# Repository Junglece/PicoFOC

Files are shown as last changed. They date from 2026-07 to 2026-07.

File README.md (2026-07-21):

# PicoFOC

**紧凑型 STM32F103 无刷电机 FOC 驱动平台**

A compact STM32F103 BLDC FOC motor drive platform — firmware, PCB, and enclosure.



---

## 项目组成 / Structure

```
PicoFOC/
├── firmware/      STM32F103 FOC 固件 (Keil MDK-ARM)
│   ├── App/       业务逻辑层
│   ├── Bsp/       板级支持包
│   ├── Drv/       驱动层
│   ├── Lib/       纯数学算法（零硬件依赖）
│   ├── Core/      CubeMX 生成代码
│   ├── Drivers/   STM32 HAL + CMSIS
│   ├── MDK-ARM/   Keil 项目文件
│   └── tools/     辅助脚本
│
├── hardware/      PCB 设计 (EasyEDA / 立创 EDA)
├── mechanical/    3D 打印外壳（适配 2804 电机）
├── LICENSE        MIT License
└── README.md
```

## 固件 / Firmware

四层架构：**LIB**（纯数学，零硬件依赖）→ **BSP**（接口 + 实现）→ **DRV**（HAL 封装）→ **APP**（业务逻辑）。

- 主控 STM32F103C8T6，无 RTOS，纯中断驱动，1 kHz 控制频率
- CAN 1 Mbps + UART 115200 双协议通信
- 双观测器方案可选：差分观测器 / 龙伯格观测器

**Firmware:** 4-layer architecture (LIB→BSP→DRV→APP). STM32F103C8T6, bare-metal interrupt-driven, 1 kHz control loop. Dual CAN + UART communication. Optional difference / Luenberger observers.

详见 [firmware/README.md](firmware/README.md)。

## 硬件 / Hardware

- **主控 MCU**：STM32F103C8T6
- **驱动芯片 Driver**：MP6541（内置三相 MOS 功率桥、驱动电路与电流采样）
- **编码器 Encoder**：AS5600（I2C，12 位磁编码器）
- **CAN 收发器 CAN transceiver**：TJA1051，单路 CAN 外设、双物理接口支持设备串联
- **终端电阻 Termination**：板载可控 120Ω CAN 终端匹配电阻
- **调试接口 Debug**：SWD 下载与在线调试
- **通信接口 Communication**：UART 串口 + CAN
- **状态指示 Status**：板载 LED 指示灯
- **接口规格 Connectors**：PH2.0 / GH1.25
- **电源系统 Power**：12V 直流输入 → DCDC 12V 转 5V → LDO 5V 转 3.3V 全板供电；**无电源防反接保护**

详见 [hardware/README.md](hardware/README.md)。

## 机械 / Mechanical

3D 打印外壳，适配 2804 电机，包含三大部件：

- **磁环座** —— 固定径向充磁磁环，配合 AS5600 编码器
- **PCB外壳1** —— 下半部分，连接 PCB 与电机
- **PCB外壳2** —— 上半部分，PCB 上盖

螺丝规格：M3 / M2.5（平头）/ M2（平头）。如需适配不同电机，需自行修改外壳模型。

**3D-printed enclosure for 2804 motors.** Three parts: magnet holder (for radial magnet + AS5600), lower case (PCB-to-motor), upper case (PCB cover). Screws: M3 / M2.5 (flat-head) / M2 (flat-head). Modify models for different motors.

详见 [mechanical/README.md](mechanical/README.md)。

## 许可证 / License

MIT License，详见 [LICENSE](LICENSE)。

第三方组件：STM32 HAL Driver (BSD-3-Clause) · CMSIS (Apache-2.0)

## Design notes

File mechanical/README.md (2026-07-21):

# PicoFOC — Mechanical

3D 外壳与结构件设计。3D-printed enclosure and structural components.

---

## 文件结构

```
mechanical/
├── 建模文件/         CAD 源文件（STEP 格式）
│   ├── 2804电机定子.step       2804 电机定子模型（装配参考）
│   ├── 2804电机转子.step       2804 电机转子模型（装配参考）
│   ├── PicoFOC驱动板.step      PicoFOC 驱动板模型（装配参考）
│   ├── PCB外壳1.step           外壳下半部分 —— 连接 PCB 与电机
│   ├── PCB外壳2.step           外壳上半部分 —— PCB 上盖
│   └── 磁环座.step             磁环座 —— 固定径向充磁磁环到电机转轴
│
├── 打印文件/         3D 打印切片文件（3MF 格式）
│   ├── PCB外壳1.3mf
│   ├── PCB外壳2.3mf
│   └── 磁环座.3mf
│
└── README.md
```

## 三大部件

### 1. 磁环座
将径向充磁的磁环固定在 2804 电机转轴上，与驱动板上的 AS5600 磁编码器配合，实现转子位置检测。

### 2. PCB外壳1（下半部分）
连接 PCB 驱动板与 2804 电机的底座。内部容纳电机定子，上部固定 PCB。

### 3. PCB外壳2（上半部分）
PCB 驱动板的上盖，保护电路元件。

## 装配螺丝

| 规格 | 说明 |
|---|---|
| M3 | 外壳固定螺丝，长度按实际固定需求选取 |
| M2.5 | 螺丝需使用平头螺丝，沉孔空间有限 |
| M2 | 螺丝需使用平头螺丝，沉孔空间有限 |

## 电机适配

当前外壳针对 2804 电机设计。如需适配不同尺寸的电机，需自行修改外壳模型。

## 建模工具

STEP 文件可用任意主流 CAD 软件打开（Fusion 360、SolidWorks、FreeCAD 等）。
3MF 文件可直接导入切片软件（Bambu Studio、Orca Slicer、PrusaSlicer 等）进行打印。

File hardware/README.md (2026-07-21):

# PicoFOC — Hardware

电机驱动板硬件设计。Motor drive board hardware design.

---

## 设计工具

EasyEDA / 立创 EDA

## 文件清单

| 文件 | 说明 |
|---|---|
| `PicoFOC.epro2` | EDA 工程源文件 |
| `PCB_PCB1_PicoFOC.pdf` | 原理图 + PCB 布局 PDF |

## 硬件规格

- **主控**：STM32F103C8T6
- **驱动芯片**：MP6541（内置三相 MOS 功率桥、驱动电路与电流采样）
- **编码器**：AS5600（I2C，12 位磁编码器）
- **CAN 收发器**：TJA1051，单路 CAN 外设、双物理接口支持设备串联
- **终端电阻**：板载可控 120Ω CAN 终端匹配电阻
- **调试接口**：SWD 下载与在线调试
- **通信接口**：UART 串口 + CAN
- **状态指示**：板载 LED 指示灯
- **接口规格**：PH2.0 / GH1.25
- **电源系统**：12V 直流输入 → DCDC 12V 转 5V → LDO 5V 转 3.3V 全板供电；**无电源防反接保护**

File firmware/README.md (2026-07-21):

# STM32F103 FOC Motor Control Firmware

基于 STM32F103C8 的磁场定向控制（FOC）无刷电机驱动固件。

Field-Oriented Control (FOC) firmware for BLDC/PMSM motors on STM32F103C8.

---

## 概述 / Overview

本项目实现了一套完整的磁场定向控制（FOC）算法，运行在 STM32F103C8T6（Cortex-M3）上，驱动无刷直流电机（BLDC/PMSM）。核心特点：

- **四层分层架构**：LIB（纯数学）→ BSP（接口定义+实现）→ DRV（外设驱动封装）→ APP（业务逻辑编排）
- **依赖注入模式**：通过函数指针接口（Observer_t、AngleSensor_t、PwmOutput_t、NvStorage_t）实现硬件解耦
- **双通信协议**：CAN（标准帧，1Mbps）+ UART（自定义帧 + CRC16-CCITT）
- **双观测器**：差分观测器 + 龙伯格观测器可选
- **无 RTOS**：纯 TIM1 中断驱动，1kHz 控制频率

This project implements a complete FOC algorithm on STM32F103C8T6 (Cortex-M3) for BLDC/PMSM motors. Features include:

- **4-layer architecture**: LIB (pure math) → BSP (interface + implementation) → DRV (peripheral wrappers) → APP (business logic)
- **Dependency injection pattern**: Hardware decoupling via function pointer interfaces (Observer_t, AngleSensor_t, PwmOutput_t, NvStorage_t)
- **Dual communication**: CAN (standard frame, 1Mbps) + UART (custom frame + CRC16-CCITT)
- **Dual observers**: Difference observer + Luenberger observer
- **No RTOS**: Bare-metal TIM1 interrupt driven, 1kHz control rate

---

## 硬件要求 / Hardware Requirements

| 组件 / Component | 型号 / Model | 说明 / Notes |
|---|---|---|
| **MCU** | STM32F103C8T6 | Blue Pill 或自定义板 |
| **电机驱动** | 3 相逆变器 | DRV8301、L6234 或分立 MOS 桥 |
| **电机** | BLDC / PMSM | 带霍尔或编码器 |
| **编码器** | AS5600 | 12 位 I2C 磁编码器，地址 0x6C |
| **CAN 收发器** | SN65HVD230 | 或兼容的 3.3V CAN 收发器 |
| **调试** | ST-Link | 编程 + 调试 |

### 引脚定义 / Pinout

| 引脚 / Pin | 功能 / Function | 说明 / Notes |
|---|---|---|
| PA0, PA1, PA2 | ADC1_IN0~2 | 电流采样（预留，当前未使用） |
| PA5 | LED | 状态指示灯（PWM 亮度 + 闪烁模式） |
| PA6, PA7, PB0 | TIM3_CH1~3 | 三相 PWM 输出，中心对齐模式 |
| PA9, PA10 | USART1_TX/RX | 串口通信（VOFA+ just-float 调试协议） |
| PA11, PA12 | CAN_RX/TX | CAN 通信（1Mbps） |
| PB1 | GPIO OUT | 电机驱动使能（高电平有效） |
| PB6, PB7 | I2C1_SCL/SDA | AS5600 磁编码器接口 |

---

## 构建指南 / Build Instructions

### 前置条件 / Prerequisites

1. **Keil MDK-ARM 5.x**（推荐 5.38 或更新版本）
2. **ARM Compiler V5.06 update 6 (build 750)**（AC5 模式）
3. **STM32F1xx 器件包**（Keil Pack Installer 中安装）

### 步骤 / Steps

1. 打开 `MDK-ARM/FOC.uvprojx`
2. 在 Project 窗口确认所有源文件已加载
3. 点击 **Build (F7)** 或 **Rebuild All**
4. 预期结果：`0 Error(s), 0 Warning(s)`

---

## 使用方法 / Usage

### 上电流程 / Startup Sequence

1. 上电后 LED 呈心跳闪烁 → 系统初始化完成
2. 发送 **校准命令**（见下方协议）→ 电机注入 Ud=4V 对齐转子，LED 快闪
3. 校准完成后自动进入 **待机模式**，LED 心跳恢复
4. 发送 **位置/速度模式命令** → LED 根据扭矩实时调节亮度

### 状态机 / State Machine

```
POWER_ON → CALIBRATE → STANDBY → RUNNING (position/speed mode)
                ↑          │
                └──────────┘ (abort or complete)
```

---

## 通信协议 / Communication Protocol

### CAN 协议 / CAN Protocol

| 参数 | 值 |
|---|---|
| 波特率 | 1 Mbps |
| 帧格式 | 标准帧，8 字节数据 |
| 控制帧 ID | `0x000 + motor_id` |
| 状态帧 ID | `0x100 + motor_id` |

**8 字节 Payload 格式：**

| 字节 | 内容 | 类型 |
|---|---|---|
| [0] | 模式 (MODE) | uint8 |
| [1-4] | 目标值 (target) | float32 LE |
| [5-6] | Kp | uint16 LE |
| [7] | Kd / Ki | uint8 |

**模式定义：**

| 值 | 模式 | 说明 |
|----|---|---|
| 0x00 | STANDBY | 待机 |
| 0x01 | SPEED | 速度模式 |
| 0x03 | POSITION | 位置模式（角度控制） |
| 0x04 | CALIBRATE | 校准 |

### UART 协议 / UART Protocol

| 参数 | 值 |
|---|---|
| 波特率 | 115200 baud |
| 数据位 | 8 |
| 停止位 | 1 |
| 校验 | 无 |

**帧格式：**

```
[0xAA] [0x08] [8 bytes payload] [CRC16-CCITT LE]
```

- 8 字节 payload 格式与 CAN 协议相同
- CRC16-CCITT（多项式 0x1021），低位在前

**示例 / Examples：**

```
待机 (Standby)    : AA 08 00 00 00 00 00 00 80 00 A6 9A
位置 0° (Position): AA 08 03 00 00 00 00 00 80 00 D3 52
位置 10°          : AA 08 03 C2 B8 32 3E 00 80 00 15 74
校准 (Calibrate)  : AA 08 04 00 00 00 00 00 80 00 CB 95
```

### VOFA+ 调试协议

UART 同时支持 VOFA+ just-float 协议，用于实时波形调试：
- 每次 FOC 控制周期输出 6 个 float（电流 Id/Iq，角度，速度，目标值等）
- 使用 VOFA+ 上位机可直接查看波形

---

## 项目架构 / Architecture

```
FOC/
├── Lib/          纯数学算法，零硬件依赖
│   ├── pid.c/h           PID 控制器
│   ├── foc_math.c/h      坐标变换（Clarke/Park）
│   ├── observer_diff.c/h  差分观测器
│   ├── observer_luenberger.c/h  龙伯格观测器
│   └── data_process.c/h  角度处理工具
│
├── Bsp/          板级支持包（接口定义 + 硬件实现）
│   ├── angle_sensor.h    角度传感器抽象接口
│   ├── angle_as5600.c/h  AS5600 编码器实现
│   ├── pwm_output.h      三相 PWM 抽象接口
│   ├── pwm_3phase.c/h    TIM3 PWM 实现
│   ├── nv_storage.h      非易失存储抽象接口
│   ├── flash_storage.c/h 片内 Flash 存储实现
│   ├── observer.h        观测器抽象接口
│   └── motor_config.h    电机参数配置
│
├── Drv/          驱动层（HAL 外设封装）
│   ├── drv_tim.c/h       定时器时基驱动
│   ├── drv_can.c/h       CAN 原始收发
│   ├── drv_adc.c/h       ADC DMA 电流采样（预留）
│   └── led_indicator.c/h LED PWM + 模式状态机
│
├── App/          应用层（业务逻辑编排）
│   ├── Foc.c/h           FOC 控制器
│   ├── motor_ctrl.c/h    控制环状态机
│   ├── motor_msg.c/h     消息总线（编解码）
│   ├── can_proto.c/h     CAN 协议层
│   └── uart_proto.c/h    UART 协议层（含 CRC16 + VOFA+）
│
├── Core/          CubeMX 生成代码
│   ├── Src/main.c         主函数（用户代码段）
│   ├── Src/*.c            外设初始化代码
│   └── Inc/*.h            外设头文件
│
├── Drivers/       STM32 HAL + CMSIS（第三方，标准库）
│
├── MDK-ARM/       Keil 项目文件
│
└── Tools/         辅助脚本
    ├── gen_uart_cmd.ps1   UART 命令帧生成（PowerShell）
    ├── gen_uart_cmd.py    UART 命令帧生成（Python）
    └── gen_uart_cmd.js    UART 命令帧生成（Node.js）
```

---

## 许可证 / License

MIT License — 详见 [LICENSE](LICENSE) 文件。

本项目包含的第三方代码：
- **STM32 HAL Driver**: BSD-3-Clause © STMicroelectronics
- **CMSIS**: Apache 2.0 © ARM Limited

---

## 相关文档 / Related

- `Tools/gen_uart_cmd.ps1` — 生成带正确 CRC 的 UART 命令帧
- 协议详情见 [通信协议](#通信协议--communication-protocol)
- 如有疑问请提交 Issue

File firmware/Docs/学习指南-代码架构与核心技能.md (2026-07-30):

# PicoFOC 学习指南 —— 代码架构、设计模式与核心技能

> 本文档是从当前项目代码中提炼出的学习路线图。
> 你原来能写 PID、能写三环、能写控制逻辑，但不擅长抽象层、函数指针、架构分层。
> 这份指南帮你补齐这些短板，让你以后写代码（哪怕是交给 AI 写）也更懂自己要什么。

---

## 目录

1. [抽象接口模式（函数指针 + 结构体）](#1-抽象接口模式函数指针--结构体)
2. [四层架构（APP / DRV / BSP / LIB）](#2-四层架构app--drv--bsp--lib)
3. [工厂函数模式](#3-工厂函数模式)
4. [回调注册机制](#4-回调注册机制)
5. [消息总线模式](#5-消息总线模式)
6. [龙伯格观测器（完整链路）](#6-龙伯格观测器完整链路)
7. [FOC 控制流水线](#7-foc-控制流水线)
8. [安全防护链](#8-安全防护链)
9. [PID 时间归一化](#9-pid-时间归一化)
10. [static 隐藏内部状态](#10-static-隐藏内部状态)

---

## 1. 抽象接口模式（函数指针 + 结构体）

**这是你跟我写代码最大的差异点，也是整个架构的基石。**

### 1.1 这个模式解决了什么问题

你原来写代码的风格：

```c
// Foc.c 中直接调 HAL_I2C
uint8_t buf[2];
HAL_I2C_Mem_Read(&hi2c1, 0x6C, 0x0C, I2C_MEMADD_SIZE_8BIT, buf, 2, 50);
float angle = ((uint16_t)buf[0] << 8 | buf[1]) * (360.0f / 4096.0f);
```

这段代码的问题：
- FOC 控制器绑死了 AS5600 编码器
- 换编码器（比如换成 TLE5012 SPI）要改 Foc.c
- 要懂 I2C 才能看懂 Foc.c

**接口模式的做法：**

```c
// Foc.c 不知道什么 AS5600，它只跟接口打交道
float raw = sensor->read_angle(sensor->ctx);
//         ↑ 函数指针
//                           ↑ 上下文（谁实现的，谁提供数据）
```

### 1.2 四步法

#### 第①步：定义接口

接口文件只放函数指针结构体，不放任何硬件头文件。

**文件：`Bsp/Inc/angle_sensor.h`**

```c
#ifndef __ANGLE_SENSOR_H__
#define __ANGLE_SENSOR_H__

typedef struct AngleSensor_t AngleSensor_t;

struct AngleSensor_t
{
    /**
     * @brief  读取机械角度（0 ~ 360°）
     * @param  ctx : 实现方的上下文（通常是 I2C 句柄）
     * @return 机械角度（度）
     */
    float   (*read_angle)(void *ctx);

    void    *ctx;   /**< 上下文指针，如 &hi2c1 */
};

#endif
```

要点：
- 用结构体把**函数指针**和**上下文指针**打包在一起
- 注释写清楚每个指针参数的语义
- `void *ctx` 是万能钥匙——任何指针都能传

项目中一共 4 个接口文件：

| 接口文件 | 函数指针 | 用途 |
|---|---|---|
| `Bsp/inc/angle_sensor.h` | `read_angle` | 读角度 |
| `Bsp/inc/pwm_output.h` | `set_duty`, `enable`, `disable` | PWM 三相输出 |
| `Bsp/inc/nv_storage.h` | `read`, `write` | 非易失存储 |
| `Bsp/inc/observer.h` | `update`, `get_position`, `get_velocity` | 角度观测器 |

#### 第②步：实现接口

写一个 **.c 文件**，实现接口中定义的函数指针。

**文件：`Bsp/Src/angle_as5600.c`**

```c
#include "angle_as5600.h"
#include "i2c.h"

#define AS5600_ADDR      0x6C
#define AS5600_ANGLE_REG 0x0C

// 这个函数签名必须跟 angle_sensor.h 中的函数指针一致：
//   float (*read_angle)(void *ctx);
float AS5600_ReadAngle(void *ctx)
{
    I2C_HandleTypeDef *hi2c = (I2C_HandleTypeDef *)ctx;
    static float last_angle = 0.0f;
    uint8_t buf[2] = {0};
    uint16_t raw;

    if (HAL_I2C_Mem_Read(hi2c, AS5600_ADDR, AS5600_ANGLE_REG,
                         I2C_MEMADD_SIZE_8BIT, buf, 2, 50) != HAL_OK)
    {
        // I2C 读失败 → 返回上次有效角度，不产生角度跳变
        return last_angle;
    }

    raw = ((uint16_t)buf[0] << 8) | buf[1];
    last_angle = (float)raw * (360.0f / 4096.0f);
    return last_angle;
}
```

注意：
- 函数签名必须跟函数指针完全一致
- `ctx` 是 `void *`，用它之前要转型回真正的类型
- 这个文件可以包含 HAL 头文件（它是实现方，需要调硬件 API）

#### 第③步：工厂函数

工厂函数把函数指针和上下文粘到一起。

```c
// 还在 angle_as5600.c 中
AngleSensor_t AS5600_Create(I2C_HandleTypeDef *hi2c)
{
    AngleSensor_t sensor;
    sensor.read_angle = AS5600_ReadAngle;   // 填入函数指针
    sensor.ctx        = (void *)hi2c;       // 保存 I2C 句柄
    return sensor;
}
```

命名规范：`XXX_Create(参数) → 返回接口结构体`。

项目中所有工厂函数：

| 工厂函数 | 参数 | 返回答 |
|---|---|---|
| `AS5600_Create(hi2c)` | I2C 句柄 | `AngleSensor_t` |
| `PWM3Phase_Create(htim)` | TIM 句柄 | `PwmOutput_t` |
| `FlashStorage_Create(addr, magic, size)` | 地址/魔数/扇区大小 | `NvStorage_t` |
| `ObserverLuenberger_Create(cfg)` | 配置结构体指针 | `Observer_t` |

#### 第④步：使用接口

业务层通过函数指针调实现，完全不关心底层。

**文件：`App/Src/Foc.c`**

```c
// FOC_Init 中保存接口指针
foc->sensor   = sensor;    // 传入的是 AngleSensor_t *
foc->motor    = motor;     // PwmOutput_t *
foc->storage  = storage;   // NvStorage_t *
foc->observer = observer;  // Observer_t *

// 使用时通过函数指针调用
void FOC_UpdateSensor(FOC_t *foc)
{
    float raw = foc->sensor->read_angle(foc->sensor->ctx);
    //              ↑ 函数指针              ↑ 上下文
    foc->observer->update(foc->observer->ctx, raw);
    foc->mech_angle = foc->observer->get_position(foc->observer->ctx);
    foc->speed      = foc->observer->get_velocity(foc->observer->ctx);
}
```

### 1.3 换硬件要怎么改

假设你想把 AS5600（I2C 编码器）换成 TLE5012（SPI 编码器）：

```diff
// 只需要改 main.c 中的工厂调用，Foc.c/motor_ctrl.c 一行不动！

- AngleSensor_t sensor = AS5600_Create(&hi2c1);
+ AngleSensor_t sensor = TLE5012_Create(&hspi1);

  // 前提：TLE5012_Create() 返回的也是 AngleSensor_t
  // TLE5012_Create() 内部实现：
  //   static float TLE5012_ReadAngle(void *ctx) {
  //       SPI_HandleTypeDef *hspi = (SPI_HandleTypeDef *)ctx;
  //       // ... SPI 读代码 ...
  //       return angle;
  //   }
  //   AngleSensor_t TLE5012_Create(SPI_HandleTypeDef *hspi) {
  //       AngleSensor_t s;
  //       s.read_angle = TLE5012_ReadAngle;
  //       s.ctx = (void *)hspi;
  //       return s;
  //   }
```

换个板子（比如 STM32G4）同样道理——你只要保证新板子上的 BSP 层实现了这几个接口，APP 层不用改。

### 1.4 你可以在自己的项目中怎么用

```c
// 1. 定义接口
typedef struct {
    float (*read_temp)(void *ctx);
    void *ctx;
} TempSensor_t;

// 2. 实现 NTC 版本
float NTC_ReadTemp(void *ctx) { /* ADC 读 NTC */ }
TempSensor_t NTC_Create(ADC_HandleTypeDef *hadc) {
    TempSensor_t s;
    s.read_temp = NTC_ReadTemp;
    s.ctx = (void *)hadc;
    return s;
}

// 3. 实现 DS18B20 版本
float DS18B20_ReadTemp(void *ctx) { /* OneWire 读 */ }
TempSensor_t DS18B20_Create(...) { ... }

// 4. 业务代码中
void ControlTemp(TempSensor_t *s) {
    float t = s->read_temp(s->ctx);
    // 不管是什么传感器，都能用
}
```

---

## 2. 四层架构（APP / DRV / BSP / LIB）

### 2.1 各层职责

```
┌──────────────────────────────────────────────────────┐
│  APP（应用层）                                         │
│  负责控制逻辑、协议编解码、任务调度                     │
│  不应直接调 HAL                                         │
│                                                        │
│  App/Inc/Foc.h        App/Src/Foc.c                    │
│  App/Inc/motor_ctrl.h  App/Src/motor_ctrl.c             │
│  App/Inc/motor_msg.h   App/Src/motor_msg.c             │
│  App/Inc/can_proto.h   App/Src/can_proto.c             │
│  App/Inc/uart_proto.h  App/Src/uart_proto.c            │
├──────────────────────────────────────────────────────┤
│  DRV（驱动层）                                          │
│  封装 STM32 外设寄存器操作，向上提供简洁 API             │
│  是所有外设操作的唯一入口                                │
│                                                        │
│  Drv/Inc/drv_tim.h     Drv/Src/drv_tim.c              │
│  Drv/Inc/drv_can.h     Drv/Src/drv_can.c              │
│  Drv/Inc/drv_adc.h     Drv/Src/drv_adc.c              │
│  Drv/Inc/led_indicator.h Drv/Src/led_indicator.c      │
├──────────────────────────────────────────────────────┤
│  BSP（板级支持包）                                      │
│  板载外设的具体实现 + 抽象接口定义                      │
│  换板子 = 换这一层                                      │
│                                                        │
│  Bsp/Inc/angle_sensor.h  Bsp/Inc/pwm_output.h         │
│  Bsp/Inc/nv_storage.h    Bsp/Inc/observer.h           │
│  Bsp/Inc/motor_config.h                                │
│  Bsp/Src/angle_as5600.c  Bsp/Src/pwm_3phase.c         │
│  Bsp/Src/flash_storage.c                               │
├──────────────────────────────────────────────────────┤
│  LIB（纯算法层）                                        │
│  零硬件依赖，纯 C 数学运算                              │
│  可以直接复制到任何平台（PC/Arduino/ESP32）              │
│                                                        │
│  Lib/Inc/pid.h          Lib/Src/pid.c                  │
│  Lib/Inc/foc_math.h     Lib/Src/foc_math.c             │
│  Lib/Inc/data_process.h Lib/Src/data_process.c         │
│  Lib/Src/observer_luenberger.c                         │
└──────────────────────────────────────────────────────┘
```

### 2.2 铁律

```
APP 可以 include: DRV, BSP, LIB
DRV 可以 include: BSP, LIB
BSP 可以 include: LIB
LIB 不 include 任何非标准库头文件（只 include <stdint.h>, <math.h> 等）

反向禁止！
  DRV 不能 include APP
  BSP 不能 include APP 或 DRV
  LIB 不能 include APP、DRV 或 BSP
```

### 2.3 为什么这样分

| 场景 | 要改的层 | 不用动的层 |
|---|---|---|
| 换单片机（F103→F405） | DRV（HAL 调用不同） | APP, BSP(接口), LIB |
| 换编码器（AS5600→TLE5012） | BSP（新建实现文件） | APP, DRV, LIB |
| 换存储介质（Flash→EEPROM） | BSP（新建实现文件） | APP, DRV, LIB |
| 改 FOC 控制算法 | APP(Foc.c) | DRV, BSP, LIB |
| 移植到 PC 仿真算法 | LIB 直接复制 | — |

---

## 3. 工厂函数模式

工厂函数是一个"构造函数"，它把实现细节隐藏在内幕，返回一个已经配置好的接口结构体。

### 3.1 标准模板

```c
// 在实现文件（.c）的末尾
ReturnType_t XX_Create(参数)
{
    static XX_Ctx_t ctx;       // 静态存储——生命周期持续到断电

    ctx.param1 = param1;       // 存入参数
    ctx.param2 = param2;

    ReturnType_t obj;
    obj.func1 = XX_Func1;      // 填入函数指针
    obj.func2 = XX_Func2;
    obj.ctx   = &ctx;          // 上下文指向内部状态

    return obj;                // 返回结构体（栈上拷贝，轻量）
}
```

### 3.2 项目中 4 个工厂函数的对比

| 工厂函数 | 内部状态（ctx 指向什么） | 初始化工作 |
|---|---|---|
| `AS5600_Create(hi2c)` | 无内部状态，ctx 直接存 I2C 句柄 | 无（HAL 已经初始化好） |
| `PWM3Phase_Create(htim)` | 无内部状态，ctx 存 TIM 句柄 | 启动三路 PWM 通道 |
| `FlashStorage_Create(addr, magic, size)` | 存 Flash 地址/魔数/扇区大小 | 无（硬件已经初始化） |
| `ObserverLuenberger_Create(cfg)` | 存 l1/l2/Ts/x2_max/x1_hat/x2_hat | 清零所有状态初始化 |

### 3.3 你以后怎么用

```c
// 不管什么硬件，统一用一个工厂函数创建实例
// 所有配置都在这一个函数调用里完成
TempSensor_t temp = NTC_Create(&hadc1);
// 或者
TempSensor_t temp = DS18B20_Create(&huart2);

// 使用的时候完全一样
float t = temp.read_temp(temp.ctx);
```

---

## 4. 回调注册机制

### 4.1 解决的问题

你原来会在中断里直接写业务逻辑：

```c
// ❌ 原来的写法：修改业务逻辑必须进中断文件
void HAL_TIM_PeriodElapsedCallback(TIM_HandleTypeDef *htim) {
    Motor_Loop();           // 业务逻辑写死在中断文件里
    HAL_GPIO_TogglePin(...); // 测试代码也混在里面
}
```

### 4.2 现在的做法

**第①步：驱动层提供注册函数**

```c
// drv_tim.c
typedef void (*TIM_Callback_t)(void);  // 回调类型

static TIM_Callback_t user_callback = NULL;  // 静态保存回调指针

void TIM_RegisterCallback(TIM_Callback_t cb) {
    user_callback = cb;     // 注册就是把函数指针存下来
}
```

**第②步：中断只调回调**

```c
// drv_tim.c
void HAL_TIM_PeriodElapsedCallback(TIM_HandleTypeDef *htim) {
    if (htim == &htim1) {
        LED_Tick();                  // 硬件相关：LED 驱动
        // ...
        if (user_callback != NULL) {
            user_callback();         // → Motor_Loop()
        }
    }
}
```

**第③步：main.c 中注册**

```c
// main.c
TIM_RegisterCallback(Motor_Loop);    // 把业务函数地址传进去
```

**CAN 也是同样的模式：**

```c
// drv_can.c
static CAN_RxCallback_t rx_callback = NULL;

void CAN_RegisterRxCB(CAN_RxCallback_t cb) {
    rx_callback = cb;
}

// 中断中：
void HAL_CAN_RxFifo0MsgPendingCallback(...) {
    if (rx_callback != NULL) {
        rx_callback(id, data);  // → CANProto_RxCallback()
    }
}

// main.c
CANProto_Init(1);  // 内部会调 CAN_RegisterRxCB
```

### 4.3 好处

- **中断文件不变**：不管业务逻辑怎么改，`stm32f1xx_it.c` 和 `drv_tim.c` 不需要再改
- **可替换**：`TIM_RegisterCallback(Motor_Loop)` 换成 `TIM_RegisterCallback(Other_Loop)` 即可切换业务
- **可空检查**：`if (cb != NULL)` 防止未注册时调空指针

---

## 5. 消息总线模式

### 5.1 架构图

```
                    ┌─────────────────────────────────────┐
                    │          motor_msg.c                │
                    │                                     │
 CAN 数据流 ──────→ │  OnFrameReceived() → 解码 → 存储    │
 UART 数据流 ─────→ │  OnFrameReceived() → 解码 → 存储    │
                    │                                     │
                    │  PollCommand() ←── motor_ctrl 每 1ms │
                    │                                     │
                    │  TxStatus() ──→ CANProto_SendPayload │
                    │  TxStatus() ──→ UARTProto_SendPayload│
                    └─────────────────────────────────────┘
```

### 5.2 数据流详解

**接收路径（主机命令 → 电机控制）：**

```
① CAN 总线收到一帧
   → CAN1_RX0_IRQHandler
     → HAL_CAN_IRQHandler
       → HAL_CAN_RxFifo0MsgPendingCallback (在 drv_can.c)
         → rx_callback(id, data)    ← 注册的是 CANProto_RxCallback
           → MotorMsg_OnFrameReceived(MSG_CH_CAN, payload)
             → 解码 payload → 存到 g_cmd
               → 设置 g_new_frame = 1

② 或 UART 收到一帧
   → USART1_IRQHandler
     → HAL_UART_IRQHandler
       → uart_rx_handler(byte)       ← UART 状态机
         → 找 0xAA → 收 8 字节 → 校验 CRC
           → MotorMsg_OnFrameReceived(MSG_CH_UART, payload)
             → 同上

③ Motor_Loop 每 1ms：
   → MotorMsg_PollCommand(&cmd)
     → g_new_frame 为真时返回解码后的指令
       → cmd.mode / cmd.target / cmd.kp / cmd.ki
```

**发送路径（电机状态 → 上位机）：**

```
① Motor_Loop 每 1ms：
   → MotorMsg_UpdateStatus(角度, 速度, Vq)
     → 编码到 g_tx_payload
    
   → MotorMsg_TxStatus()
     → CANProto_SendPayload(g_tx_payload)  ← 总是发
     → if (UART模式) UARTProto_SendPayload(g_tx_payload)
```

### 5.3 双模切换

```c
// motor_msg.c
static uint32_t g_last_can_rx = 0;

void MotorMsg_OnFrameReceived(MotorMsg_Channel_t ch, const uint8_t data[8]) {
    if (ch == MSG_CH_CAN) {
        g_last_can_rx = HAL_GetTick();  // 记录 CAN 最后收帧时间
    }
    // ... 解码 ...
}

// 判断当前通信模式
uint8_t MotorMsg_IsCANMode(void) {
    return (HAL_GetTick() - g_last_can_rx) < 500;  // 500ms 超时
}
```

| 模式 | 条件 | CAN 自定义协议 | UART 自定义协议 | VOFA+ 调试 |
|---|---|---|---|---|
| CAN 模式 | 500ms 内收到过 CAN 帧 | ✓ 发 | ✗ 停发 | ✓ 全速发 |
| UART 模式 | 超过 500ms 没收 CAN | ✓ 发（可共存） | ✓ 发 | ✗ 停发 |

---

## 6. 龙伯格观测器（完整链路）

### 6.1 它解决什么

编码器读到的角度中混杂了噪声（I2C 通信噪声、量化误差、振动）。

你原来的做法——差分法：

```
speed = (angle_now - angle_last) × frequency × 6
```

如果角度有 ±1° 的噪声，在 1kHz 控制频率下速度噪声 = ±6000°/s = ±1000rpm。速度环看到这么大的噪声波动，输出会剧烈抖动。

龙伯格观测器的做法：

```
内部维护一个"模型"，模型自己会推演位置和速度
用实测角度去"修正"模型的推演结果
模型输出的位置和速度天然平滑（就像一个有惯性的滤波）
```

### 6.2 数学模型

**二阶状态空间模型：**

```
状态向量 x = [x1  ]    x1 = 估计位置 (度)
             [x2]      x2 = 估计速度 (rpm)

每个控制周期（Ts = 1/1000 = 0.001s 做两件事：

① 预测（先验估计）——用物理模型推演
  x1_k+1 = x1_k + Ts × x2_k × 6   ← 位置增量 = 速度 × 6(deg/s per rpm) × Ts
  x2_k+1 = x2_k                     ← 速度不变（匀速假设）

② 校正（后验修正）——用实测角度纠偏
  error = y_k - x1_k                ← y_k = 实测角度
  x1_k+1 += l1 × error              ← 位置偏差按 l1 比例修正
  x2_k+1 += l2 × error              ← 速度偏差按 l2 比例修正
```

### 6.3 完整代码

```c
// Lib/Src/observer_luenberger.c

// 内部状态
typedef struct {
    float x1_hat;   // 估计位置 (deg)
    float x2_hat;   // 估计速度 (rpm)
    float l1, l2;   // 校正增益
    float Ts;       // 采样周期 (s)
    float x2_max;   // 速度限幅
} ObserverLuenbergerCtx_t;

// 核心更新函数——每 1ms 调一次
static void luenberger_update(void *ctx, float raw_angle_deg)
{
    ObserverLuenbergerCtx_t *c = (ObserverLuenbergerCtx_t *)ctx;

    // 误差 = 实测 - 估计（取最短路径，不是简单减法）
    float error = ANGLE_limit(raw_angle_deg - c->x1_hat, 360.0f, -180.0f, 180.0f);

    // 预测 + 校正（合在一起写了）
    // rpm × 6 = deg/s, deg/s × Ts = deg
    c->x1_hat += c->Ts * c->x2_hat * 6.0f + c->l1 * error;
    c->x1_hat  = ANGLE_limit(c->x1_hat, 360.0f, 0.0f, 360.0f);

    c->x2_hat += c->l2 * error;
    c->x2_hat  = DATA_limit(c->x2_hat, -c->x2_max, c->x2_max);
}
```

### 6.4 调用链路

```
main.c 初始化：
  Observer_t angle_obs = ObserverLuenberger_Create(&obs_cfg);
  FOC_Init(&Motor, ..., &angle_obs);

每 1ms 控制周期（Motor_Loop → FOC_UpdateSensor）：
  
  ① foc->sensor->read_angle(foc->sensor->ctx)     ← AS5600 读原始角度
                    │
  ② foc->observer->update(ctx, raw_angle)         ← 喂给观测器
                    │
  ③ foc->observer->get_position(ctx)               ← 拿滤波后角度
     foc->observer->get_velocity(ctx)               ← 拿估计速度
                    │
  ④ 这两个值进入控制环：
     foc->mech_angle → 位置环 PD
     foc->speed      → 速度环 PI
```

### 6.5 调参指南

```c
ObserverLuenberger_Config obs_cfg = {
    .rate_hz   = 1000.0f,     // 控制频率
    .l1        = 0.14f,       // 位置校正增益
    .l2        = 100.0f,      // 速度校正增益
    .speed_max = 10000.0f,    // 速度限幅
};
```

| 应用场景 | l1 | l2 | 效果 | 适合 |
|---|---|---|---|---|
| 平衡模式 | 0.14 | 100 | 滤波和响应均衡 | 多数情况 |
| 重滤波 | 0.05 | 0.5 | 速度平滑但滞后 | 传感器噪声大 |
| 快响应 | 0.20 | 5.0 | 快速跟踪，速度有小抖动 | 外部扰动大 |
| 高刚度位置环 | 0.50 | 1.0 | 位置跟踪滞后 ~2ms | 位置模式 |

运行时动态调参：

```c
// 跑的过程中想改增益，不用重建
ObserverLuenberger_SetGain(&angle_obs, 0.2f, 150.0f);
```

### 6.6 换观测器

```c
// main.c —— 就换一行工厂函数
// 差分法：
// Observer_t angle_obs = ObserverDiff_Create(FOC_RATE_HZ);

// 龙伯格（当前）：
Observer_t angle_obs = ObserverLuenberger_Create(&obs_cfg);

// 卡尔曼（预留，接口相同）：
// Observer_t angle_obs = ObserverKalman_Create(&kalman_cfg);

// FOC_Init 中只保存 observer 指针，不管具体算法
```

---

## 7. FOC 控制流水线

### 7.1 单周期流水线

每 1ms，`Motor_Loop` 执行以下步骤：

```
① FOC_UpdateSensor(&Motor)
   └─→ sensor->read_angle() → observer->update() → get_position/get_velocity

② FOC_ReadCurrents(&Motor)          [封存，恒输出 0]
   └─→ 读 ADC → Clarke 变换 → Park 变换 → Id / Iq
        （当前无电流反馈，全部返回 0）

③ 控制环（根据模式选执行）：
   ┌─ 位置模式：FOC_PosCtrl(&Motor) + FOC_SpdCtrl(&Motor)
   │    位置 PD → 目标速度 → 速度 PI → Uq
   │
   ├─ 速度模式：FOC_SpdCtrl_Ext(&Motor)
   │    速度 PI（独立的 PID 参数）→ Uq
   │
   ├─ 待机模式：什么都不做（不调 FOC_Output）
   │
   └─ 校准模式：FOC_Output 中检测到 calib_flag, 自动注入 Ud=4V

④ FOC_Output(&Motor)
   └─→ 电角度前馈补偿
     └─→ (Ud, Uq) 矢量限幅（防止过调制）
       └─→ InvPark 变换：d-q → α-β
         └─→ InvClarke SVPWM：α-β → 三相电压
           └─→ 归一化 [0,1] → motor->set_duty()
```

### 7.2 关键数学变换

**反 Park 变换（d-q → α-β）：**

```
Ualpha = Ud × cos(θ) - Uq × sin(θ)
Ubeta  = Uq × cos(θ) + Ud × sin(θ)

其中 θ = 电角度 + 前馈补偿角度
```

**SVPWM（零序分量注入法）：**

```
① 用反 Clarke 算出三相电压（不含直流偏置）
② 找三相中的 Vmax 和 Vmin
③ Vzero = (Vmax + Vmin) / 2    ← 零序分量
④ Va -= Vzero; Vb -= Vzero; Vc -= Vzero;  ← 每相减去零序
⑤ 再叠加 Udc/2 偏置，使范围到 [0, Udc]
⑥ 归一化到 [0, 1] 输出给 PWM

等价于经典 SVPWM，但不需要扇区判断和切换时间计算。
直流利用率 ~100%（对比 SPWM 的 86.6%）。
```

### 7.3 电角度前馈补偿

```
问题：从 AS5600 采样到 PWM 输出生效，总共延迟 ~210μs
      高速时（比如 2000rpm, 7 极对）, 转子在此期间转过：
      2000 × 7 × 6 × 0.00021 = 17.6° 电角度
      如果不补偿，电压矢量滞后转子 17.6°，部分电压跑到 d 轴

补偿方法：
  FOC_Output 中，先用当前速度算出补偿角度
  加到电角度上再做反 Park 变换
  
代码（Foc.c）：
  float angle_advance = speed × pole_pairs × 6 × ANGLE_COMP_DELAY_S;
  float comp_elec_angle = foc->elec_angle + angle_advance;
  FOC_Math_InvPark(Ud, Uq, comp_elec_angle * DEG_TO_RAD, ...);
```

---

## 8. 安全防护链

### 8.1 三层防护

```
第一层：通信超时（软件）
  位置/速度模式下 100ms 没收指令 → 自动待机关断

第二层：异常中断（硬件+软件）
  NMI / HardFault / BusFault / MemManage / UsageFault
  全部做的第一件事：PB1 拉低（关 MP6541）

第三层：独立看门狗（硬件）
  2s 不喂狗 → MCU 自动复位
```

### 8.2 看门狗配置

```c
static void IWDG_Init(void)
{
    // ① 开启 LSI 时钟
    RCC->CSR |= RCC_CSR_LSION;
    while (!(RCC->CSR & RCC_CSR_LSIRDY));

    // ② 解锁
    IWDG->KR = 0x5555U;

    // ③ 预分频 /256: 40kHz / 256 = 156.25Hz
    IWDG->PR = 0x06U;

    // ④ 重装载 312: 312 / 156.25 = ~2.0s
    IWDG->RLR = 0x0138U;

    // ⑤ 刷新 + 启动
    IWDG->KR = 0xAAAAU;   // 刷新
    IWDG->KR = 0xCCCCU;   // 启动
}
```

喂狗点：
```c
// while(1) 主循环中
while (1) {
    IWDG_REFRESH();
    VOFA_SendDebug();
}

// Motor_Loop 每 1ms 周期
void Motor_Loop(void) {
    IWDG_REFRESH();   // 如果这里卡死，2s 后 WDT 复位
    // ...
}
```

---

## 9. PID 时间归一化

### 9.1 区别

```c
// ❌ 你原来的写法——积分累加不乘 dt，Ki 值依赖频率
pid->integral += error;
output = kp * error + ki * integral + kd * derivative;

// ✅ 现在的写法——积分乘 dt，Ki 值与频率无关
pid->integral += error * dt;     // dt = 1/rate
output = kp * error + ki * integral + kd * (differential / dt);
```

### 9.2 好处

如果你把 FOC_RATE_HZ 从 1000Hz 改成 500Hz：

- **旧的写法**：积分累加速率减半，Ki 效果实际翻倍，要重新调参
- **现在的写法**：`integral += error × dt` 中 dt 也翻倍了，Ki 效果完全不变

### 9.3 Derivative-on-Measurement

```c
// 旧写法——微分项 = Kd × (error - last_error)
// 目标值突变时 error 跳变 → 微分冲击
pid->differential = error - last_error;

// 新写法——微分项 = Kd × Δ测量值
// 目标值突变不影响微分项，只有测量值变化才会产生微分作用
pid->differential = measure_error;  // 当前位置 - 上次位置
// 位置环中：传入 -angle_delta 起阻尼作用
float angle_delta = mech_angle - last_mech_angle;
PID_Calc(&PosPID, error, -angle_delta);
```

---

## 10. static 隐藏内部状态

### 10.1 原则

```c
// 头文件中只放函数声明
// .c 文件中用 static 隐藏所有内部变量和辅助函数

// ❌ 不好——头文件中暴露内部变量
// drv_adc.h:
extern int16_t adc_dma_buf[3];  // 谁都能改

// ✅ 好——头文件只放 API 声明
// drv_adc.h:
void ADC_ReadPhaseCurrents(ADC_PhaseCurrents_t *currents);

// drv_adc.c:
static int16_t s_adc_dma_buf[3] = {0};    // 外部不可见
static int16_t s_adc_snapshot[3] = {0};
```

### 10.2 好处

- **可控的访问入口**：要读 ADC 数据只能通过 `ADC_GetRawCurrents()`，而不是直接读写数组
- **重构安全**：内部实现改了（比如数组大小变了），不影响外部调用代码
- **命名空间干净**：IDE 提示时不会看到一堆内部变量

---

## 总结：你应该带走的核心技能

| 技能 | 重要性 | 一句话说明 |
|---|---|---|
| 抽象接口模式 | ⭐⭐⭐ | 用 struct{函数指针; void *ctx} 把"干什么"和"怎么干"分离 |
| 四层架构 | ⭐⭐⭐ | APP/DRV/BSP/LIB，上层调下层，下层不能调上层 |
| 工厂函数 | ⭐⭐⭐ | `XXX_Create(参数) → 接口结构体`，对象的构造器 |
| 回调注册 | ⭐⭐ | 中断中不写业务逻辑，用 `RegisterCallback(func)` 挂上去 |
| 消息总线 | ⭐⭐ | 所有通信数据统一入口、统一解码，业务不需要知道来源 |
| static 封装 | ⭐⭐ | 内部变量用 static 隐藏，只通过 API 函数暴露 |
| 时间归一化 | ⭐⭐ | `integral += error × dt`，Ki 不再跟频率绑定 |
| 龙伯格观测器 | ⭐⭐ | 内部模型预测 + 实测值校正 → 平滑的位置和速度 |
| FOC 数学 | ⭐ | 反 Park → SVPWM 零序注入 → 归一化输出 |
| 前馈补偿 | ⭐ | 用当前速度推算延迟期间的角度偏移，提前补偿到输出角度 |

> **核心一条：** 以后再写代码，先想"这个功能将来会不会换硬件实现？"。如果会 → 用接口模式。
> 接口模式就三行——一个结构体、几个函数指针、一个 void *ctx。你完全能掌握。

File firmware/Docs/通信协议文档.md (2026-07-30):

# PicoFOC 通信协议文档

> 本文档描述 PicoFOC 电机控制器与上位机之间的通信协议。
> | 版本 | 日期 | 说明 |
> |------|------|------|
> | 1.2 | 2026-07-30 | 重构文档结构，新增编解码速查 + CRC16 参考实现 + 附录流程；修正 3.2 遗留的 `655.34` 系数 |
> | 1.1 | 2026-07-28 | VOFA 通道重映射；IWDG 初始化文档化 |
> | 1.0 | 2026-07-22 | 初始整理 |

---

## 1. 协议总览

### 1.1 双通信介质

PicoFOC 支持 **CAN** 和 **UART** 两种物理通信介质，两者独立运行、共用同一套 payload 格式。

| 介质 | 参数 | MCU 引脚 |
|---|---|---|
| CAN | 1 Mbps，标准帧（11 位 ID），8 字节数据 | PA11(RX), PA12(TX) |
| UART | 115200 8N1 | PA10(RX), PA9(TX) |

### 1.2 统一 8 字节 Payload 设计

CAN 和 UART 的**核心数据格式完全一致**——8 字节 payload 结构相同，编解码共用 `motor_msg.c` 同一套代码：

```
上位机 ──→ 电机 : [8 字节控制帧]   (RX 方向)
电机   ──→ 上位机 : [8 字节状态帧]   (TX 方向)
```

| 介质 | RX 控制帧 | TX 状态帧 |
|---|---|---|
| CAN | 裸 8 字节（ID=0x000+电机ID） | 裸 8 字节（ID=0x100+电机ID） |
| UART | `[0xAA][0x08][payload][CRC16]` | 同左 |

---

## 2. RX 控制帧（上位机 → 电机）

### 2.1 8 字节 Payload 布局

```
偏移:  [0]        [1][2][3][4]       [5][6]         [7]
      ┌──────────┬──────────────────┬──────────────┬──────────┐
      │  mode    │     target       │   kp_raw     │ kd_raw   │
      │  uint8   │   float32 LE     │  uint16 LE   │  uint8   │
      └──────────┴──────────────────┴──────────────┴──────────┘
```

### 2.2 mode — 运行模式（byte [0]）

| 值 | 名称 | 说明 |
|----|---|---|
| 0 | STANDBY | 待机，关断驱动芯片，PWM 停止，PID 积分清零 |
| 1 | TORQUE | 力矩模式（预留，未实现） |
| 2 | SPEED | 速度模式（独立速度 PI 环，使用 SpdPID_Ext） |
| 3 | POSITION | 位置模式（串级：位置 PD → 速度 PI） |
| 4 | CALIBRATE | 电角度自校准 |

> **边界处理：** 在 CAN/UART 协议层（收发回调中）做 `data[0] <= 4` 检查，mode 值 > 4 的帧**静默丢弃**。

### 2.3 target — 目标值（bytes [1..4]）

IEEE 754 **单精度浮点数、小端字节序**。单位取决于当前模式：

| 模式 | 物理含义 | 输入单位 | 内部换算 |
|---|---|---|---|
| SPEED | 目标机械角速度 | **rad/s** | `rpm = target × 9.5493` |
| POSITION | 目标机械角度 | **rad** | `deg = target × 57.2958` |
| CALIBRATE | 忽略 | — | — |
| STANDBY | 忽略 | — | — |

> **边界处理：** 解码后检查 IEEE 754 指数位（`0x7F800000`），NaN/Inf 自动替换为 0.0。

**常用角度换算表：**

| 角度 | 弧度 (float32) | 编码 HEX (LE) |
|---|---|---|
| 0° | 0.0 | `00 00 00 00` |
| 45° | 0.785398 | `49 0F C9 3F` |
| 90° | 1.570796 | `DB 0F C9 3F` |
| 180° | 3.141593 | `DB 0F 49 40` |
| 270° | 4.712389 | `DB 0F 96 40` |
| 280° | 4.886922 | `AA 61 9C 40` |
| 320° | 5.585054 | `C2 B8 B2 40` |
| 340° | 5.934119 | `4E E4 BD 40` |
| 360° | 6.283185 | `DB 0F C8 40` |

### 2.4 kp_raw — 比例增益（bytes [5..6]）

uint16 **小端**，**同时**设置位置环 Kp 和速度环 Kp。

| 属性 | 值 |
|---|-----|
| 解码公式 | `kp_float = raw × 0.00015259` |
| 编码公式 | `raw = round(kp_float / 0.00015259)` |
| 系数推导 | `10.0 / 65535 ≈ 0.00015259` |
| kp 范围 | **0.0 ~ 10.0** |
| raw 范围 | 0 ~ 65535 |
| 分辨率 | ~0.00015 |

**常用值速查：**

| kp_float | raw | HEX (LE) |
|---|-----|---|
| 0.0 | 0 | `00 00` |
| 0.01 | 66 | `42 00` |
| 0.05 | 328 | `48 01` |
| 1.0 | 6554 | `9A 19` |
| 3.0 | 19661 | `4D 4C` |
| **5.0** | **32768** | **`00 80`** |
| 10.0 | 65535 | `FF FF` |

### 2.5 kd_raw — 微分/积分增益（byte [7]）

一个 uint8 **同时编码**位置环 Kd 和速度环 Ki。

| 属性 | 值 |
|---|-----|
| 解码公式 | `kd_float = raw × 0.00392157`（写 pos_kd 和 spd_ki） |
| 编码公式 | `raw = round(kd_float / 0.00392157)` |
| 系数推导 | `1.0 / 255 ≈ 0.00392157` |
| kd/ki 范围 | **0.0 ~ 1.0** |
| raw 范围 | 0 ~ 255 |
| 分辨率 | ~0.00392 |

**常用值速查：**

| kd/ki_float | raw | HEX |
|---|-----|-----|
| 0.0 | 0 | `00` |
| 0.004 | 1 | `01` |
| 0.01 | 3 | `03` |
| 0.1 | 26 | `1A` |
| 0.5 | 128 | `80` |
| 1.0 | 255 | `FF` |

> ⚠️ **已知限制：** Kd 和 Ki 共用同一字节，无法独立设置。调位置环阻尼的同时会改变速度环积分，反之亦然。

### 2.6 CAN 控制帧

```
CAN ID = 0x000 + 电机ID  （标准帧，11 位）
默认（电机ID=1）：ID = 0x001
```

8 字节 payload 直接放入 CAN 数据场发送，**无额外帧头**。

### 2.7 UART 控制帧（完整 12 字节）

```
偏移: [0]    [1]    [2..9]          [10..11]
     ┌──────┬──────┬────────────────┬────────────┐
     │ 0xAA │ 0x08 │ 8-byte payload │ CRC16-CCITT│
     │ 帧头  │ 长度  │ （同 CAN）     │  小端       │
     └──────┴──────┴────────────────┴────────────┘
```

- **帧头（SOF）：** `0xAA`，用于接收状态机同步
- **长度字段：** 固定 `0x08`
- **CRC16-CCITT：** 对 SOF + LEN + 8 字节 payload 共 **10 字节**计算，小端存放
  - 多项式：`0x1021`，初始值：`0xFFFF`
  - 参考实现见第 [7 节](#7-crc16-ccitt-实现)
- **接收流程：** UART 中断 → 逐字节状态机 → 找 `0xAA` → 读长度 → 收 8 字节 payload → 收 2 字节 CRC → 校验 → 通过则解码
- **错误处理：** CRC 失败、长度不为 `0x08`、mode > 4 → 静默丢弃，状态机复位

---

## 3. TX 状态帧（电机 → 上位机）

### 3.1 8 字节 Payload 布局

```
偏移: [0..1]         [2..3]         [4..5]         [6..7]
     ┌──────────────┬──────────────┬──────────────┬──────────────┐
     │  位置 raw    │  速度 raw    │  Vq raw      │   保留       │
     │   int16 LE   │   int16 LE   │  int16 LE    │   = 0x0000  │
     └──────────────┴──────────────┴──────────────┴──────────────┘
```

编码通式：`raw = (int16_t)(物理量 × 编码系数)`

### 3.2 位置反馈（bytes [0..1]）

| 属性 | 值 |
|---|-----|
| 编码公式 | `raw = pos_rad × 834.4` |
| 解码公式 | `pos_rad = raw / 834.4` → `pos_deg = pos_rad × 57.2958` |
| 系数推导 | `32767 / (12.5 × π) ≈ 834.4` |
| 可编码范围 | **±39.27 rad（≈ ±2250°，约 6.25 圈）** |
| 分辨率 | **0.0012 rad ≈ 0.069°** |

### 3.3 速度反馈（bytes [2..3]）

| 属性 | 值 |
|---|-----|
| 编码公式 | `raw = speed_rads × 131.07` |
| 解码公式 | `speed_rads = raw / 131.07` → `rpm = speed_rads × 9.5493` |
| 系数推导 | `32767 / 250 ≈ 131.07` |
| 可编码范围 | **±250 rad/s（≈ ±2387 rpm）** |
| 分辨率 | **0.0076 rad/s ≈ 0.073 rpm** |

> 量程变更历史：2026-07-25 从 `655.34`（±477.5 rpm）改为 `131.07`（±2387 rpm）。

### 3.4 Vq 反馈（bytes [4..5]）

| 属性 | 值 |
|---|-----|
| 编码公式 | `raw = vq × 819.175` |
| 解码公式 | `vq = raw / 819.175` |
| 系数推导 | `32767 / 40 ≈ 819.175` |
| 可编码范围 | **±40 V** |
| 分辨率 | **0.00122 V** |

> 实际母线 12V，Vq 限幅在 ±12V，远在量程内，无饱和风险。

### 3.5 CAN 状态帧

```
CAN ID = 0x100 + 电机ID（标准帧，11 位）
默认（电机ID=1）：ID = 0x101
```

### 3.6 UART 状态帧

格式与 [2.7 UART 控制帧](#27-uart-控制帧完整-12-字节) 完全相同：`[0xAA][0x08][payload][CRC16 LE]`。

### 3.7 发送策略（双模自动切换）

状态帧每 1ms 发一次，CAN 和 UART 的发送策略不同：

```
每 1ms 控制周期：
  CANProto_SendPayload(payload)    ← 始终发送（CAN 总线 1kHz）
  if (UART 模式)                    ← 仅 500ms 内没收到 CAN 帧时
    UARTProto_SendPayload(payload)
```

**模式判定（500ms 超时）：**

| 模式 | 条件 | CAN 状态帧 | UART 自定义协议 | VOFA+ 调试 |
|---|---|---|---|---|
| **CAN 模式** | 最近 500ms 内收过 CAN 帧 | 1kHz ✓ | 停发 ✗ | 全速 ✓ |
| **UART 模式** | 超过 500ms 没收 CAN | 1kHz ✓ | 1kHz ✓ | 停发 ✗ |

---

## 4. VOFA+ 调试通道

### 4.1 帧格式

独立于自定义协议之上，与自定义协议**共用同一根 UART 线**。

```
[N × float32 (4N bytes)] [0x00, 0x00, 0x80, 0x7f]
  channel data              VOFA+ just-float 帧尾
```

- N = 8 通道，共 **36 字节/帧**
- 帧尾是 IEEE 754 的 +Inf（解释为 float 时 ≈ 1.1755e-38 非规范化数），VOFA+ 用它识别帧结束
- **同线共存：**
  - 自定义协议以 `0xAA` 开头 → VOFA+ 看到 `0xAA` 当无效浮点数忽略
  - VOFA 帧不以 `0xAA` 开头 → 自定义协议上位机（按 CRC 过滤）丢弃
  - `uart_tx_busy` 互斥锁防止两者同时发送

### 4.2 通道映射

| 通道 | 变量 | 单位 |
|---|---|---|
| ch0 | `Motor.mech_angle` | °（机械角度，观测器滤波后） |
| ch1 | `Motor.target_angle` | °（目标角度） |
| ch2 | `Motor.speed` | rpm（实际转速） |
| ch3 | `Motor.target_speed` | rpm（目标转速） |
| ch4 | `Motor.Uq` | V（交轴电压） |
| ch5 | `(float)MotorMsg_GetLastMode()` | —（运行模式 0~4） |
| ch6 | `MotorMsg_GetLastTarget()` | rad/rpm/Nm（最近指令目标值） |
| ch7 | `0.0f` | —（保留） |

### 4.3 发送条件

- **仅 CAN 模式**下发送（UART 模式停发，让出带宽给自定义协议）
- 由 `main.c` 的 `while(1)` 循环全速驱动
- 受 `uart_tx_busy` 互斥锁限制，实际约 1~2kHz

---

## 5. 常用指令速查表

### 5.1 CAN 帧（8 字节 payload，CAN ID = 0x001）

| 命令 | 8 字节 Payload (HEX) | 说明 |
|---|---|---|
| 待机 | `00 00 00 00 00 00 00 00` | mode=0 |
| 速度 50 rad/s ~477 rpm | `02 00 00 48 42 42 00 01` | kp=0.01, ki=0.004 |
| 位置 0° | `03 00 00 00 00 00 80 00` | kp=5.0 |
| 位置 45° | `03 49 0F C9 3F 00 80 00` | kp=5.0 |
| 位置 90° | `03 DB 0F C9 3F 00 80 00` | kp=5.0 |
| 位置 180° | `03 DB 0F 49 40 00 80 00` | kp=5.0 |
| 位置 280° | `03 AA 61 9C 40 00 80 00` | kp=5.0 |
| 位置 320° | `03 C2 B8 B2 40 00 80 00` | kp=5.0 |
| 位置 340° | `03 4E E4 BD 40 00 80 00` | kp=5.0 |
| 校准 | `04 00 00 00 00 00 80 00` | — |

### 5.2 UART 完整帧（12 字节）

| 命令 | 完整帧 (HEX) |
|---|---|
| 待机 | `AA 08 00 00 00 00 00 00 00 00 8A D1` |
| 速度 50 rad/s | `AA 08 02 00 00 48 42 42 00 01 EB BA` |
| 位置 0° | `AA 08 03 00 00 00 00 00 80 00 D3 52` |
| 位置 90° | `AA 08 03 DB 0F C9 3F 00 80 00 07 02` |
| 位置 180° | `AA 08 03 DB 0F 49 40 00 80 00 0B B4` |
| 位置 280° | `AA 08 03 AA 61 9C 40 00 80 00 0E 2A` |
| 校准 | `AA 08 04 00 00 00 00 00 80 00 CB 95` |

---

## 6. 编码系数速查表

| 方向 | 字段 | 公式 | 系数 | 推导 |
|---|---|---|---|---|
| **RX** | Kp | `float = raw × 系数` | **0.00015259** | `10.0 / 65535` |
| **RX** | Kd/Ki | `float = raw × 系数` | **0.00392157** | `1.0 / 255` |
| **TX** | 位置 | `raw = pos_rad × 系数` | **834.4** | `32767 / (12.5×π)` |
| **TX** | 速度 | `raw = speed_rads × 系数` | **131.07** | `32767 / 250` |
| **TX** | Vq | `raw = vq × 系数` | **819.175** | `32767 / 40` |

---

## 7. CRC16-CCITT 实现

用于 UART 帧校验（多项式 `0x1021`，初始值 `0xFFFF`）。

```c
/**
 * CRC16-CCITT 查表法
 * 输入数据：SOF(0xAA) + LEN(0x08) + 8-byte payload = 10 字节
 * 输出：16 位 CRC，小端存储（低字节在前，高字节在后）
 */

static const uint16_t crc16_table[256] = {
    0x0000, 0x1021, 0x2042, 0x3063, 0x4084, 0x50A5, 0x60C6, 0x70E7,
    0x8108, 0x9129, 0xA14A, 0xB16B, 0xC18C, 0xD1AD, 0xE1CE, 0xF1EF,
    0x1231, 0x0210, 0x3273, 0x2252, 0x52B5, 0x4294, 0x72F7, 0x62D6,
    0x9339, 0x8318, 0xB37B, 0xA35A, 0xD3BD, 0xC39C, 0xF3FF, 0xE3DE,
    0x2462, 0x3443, 0x0420, 0x1401, 0x64E6, 0x74C7, 0x44A4, 0x5485,
    0xA56A, 0xB54B, 0x8528, 0x9509, 0xE5EE, 0xF5CF, 0xC5AC, 0xD58D,
    0x3653, 0x2672, 0x1611, 0x0630, 0x76D7, 0x66F6, 0x5695, 0x46B4,
    0xB75B, 0xA77A, 0x9719, 0x8738, 0xF7DF, 0xE7FE, 0xD79D, 0xC7BC,
    0x48C4, 0x58E5, 0x6886, 0x78A7, 0x0840, 0x1861, 0x2802, 0x3823,
    0xC9CC, 0xD9ED, 0xE98E, 0xF9AF, 0x8948, 0x9969, 0xA90A, 0xB92B,
    0x5AF5, 0x4AD4, 0x7AB7, 0x6A96, 0x1A71, 0x0A50, 0x3A33, 0x2A12,
    0xDBFD, 0xCBDC, 0xFBBF, 0xEB9E, 0x9B79, 0x8B58, 0xBB3B, 0xAB1A,
    0x6CA6, 0x7C87, 0x4CE4, 0x5CC5, 0x2C22, 0x3C03, 0x0C60, 0x1C41,
    0xEDAE, 0xFD8F, 0xCDEC, 0xDDCD, 0xAD2A, 0xBD0B, 0x8D68, 0x9D49,
    0x7E97, 0x6EB6, 0x5ED5, 0x4EF4, 0x3E13, 0x2E32, 0x1E51, 0x0E70,
    0xFF9F, 0xEFBE, 0xDFDD, 0xCFFC, 0xBF1B, 0xAF3A, 0x9F59, 0x8F78,
    0x9188, 0x81A9, 0xB1CA, 0xA1EB, 0xD10C, 0xC12D, 0xF14E, 0xE16F,
    0x1080, 0x00A1, 0x30C2, 0x20E3, 0x5004, 0x4025, 0x7046, 0x6067,
    0x83B9, 0x9398, 0xA3FB, 0xB3DA, 0xC33D, 0xD31C, 0xE37F, 0xF35E,
    0x02B1, 0x1290, 0x22F3, 0x32D2, 0x4235, 0x5214, 0x6277, 0x7256,
    0xB5EA, 0xA5CB, 0x95A8, 0x8589, 0xF56E, 0xE54F, 0xD52C, 0xC50D,
    0x34E2, 0x24C3, 0x14A0, 0x0481, 0x7466, 0x6447, 0x5424, 0x4405,
    0xA7DB, 0xB7FA, 0x8799, 0x97B8, 0xE75F, 0xF77E, 0xC71D, 0xD73C,
    0x26D3, 0x36F2, 0x0691, 0x16B0, 0x6657, 0x7676, 0x4615, 0x5634,
    0xD94C, 0xC96D, 0xF90E, 0xE92F, 0x99C8, 0x89E9, 0xB98A, 0xA9AB,
    0x5844, 0x4865, 0x7806, 0x6827, 0x18C0, 0x08E1, 0x3882, 0x28A3,
    0xCB7D, 0xDB5C, 0xEB3F, 0xFB1E, 0x8BF9, 0x9BD8, 0xABBB, 0xBB9A,
    0x4A75, 0x5A54, 0x6A37, 0x7A16, 0x0AF1, 0x1AD0, 0x2AB3, 0x3A92,
    0xFD2E, 0xED0F, 0xDD6C, 0xCD4D, 0xBDAA, 0xAD8B, 0x9DE8, 0x8DC9,
    0x7C26, 0x6C07, 0x5C64, 0x4C45, 0x3CA2, 0x2C83, 0x1CE0, 0x0CC1,
    0xEF1F, 0xFF3E, 0xCF5D, 0xDF7C, 0xAF9B, 0xBFBA, 0x8FD9, 0x9FF8,
    0x6E17, 0x7E36, 0x4E55, 0x5E74, 0x2E93, 0x3EB2, 0x0ED1, 0x1EF0,
};

uint16_t CRC16_CCITT(const uint8_t *data, uint32_t len)
{
    uint16_t crc = 0xFFFF;
    for (uint32_t i = 0; i < len; i++)
    {
        crc = (crc << 8) ^ crc16_table[((crc >> 8) ^ data[i]) & 0xFF];
    }
    return crc;
}
```

> 位运算版本（适用于查表空间受限的场景）：
> ```c
> uint16_t CRC16_CCITT(const uint8_t *data, uint32_t len) {
>     uint16_t crc = 0xFFFF;
>     for (uint32_t i = 0; i < len; i++) {
>         crc ^= (uint16_t)data[i] << 8;
>         for (int j = 0; j < 8; j++)
>             crc = (crc & 0x8000) ? (crc << 1) ^ 0x1021 : (crc << 1);
>     }
>     return crc;
> }
> ```

---

## 8. 已知问题

| # | 问题 | 影响 | 备注 |
|---|---|---|---|
| 1 | byte[7] 同时编码 pos_kd 和 spd_ki | 无法独立调位置环阻尼和速度环积分 | 需扩展 payload 或用参数分组指令 |
| 2 | ~~速度反馈范围不足~~ | ~~已修复 2026-07-25~~ | 系数 655.34 → 131.07，量程扩至 ±2387 rpm |
| 3 | ~~NaN/Inf 未校验~~ | ~~已修复 2026-07-26~~ | DecodeCommand 中增加指数位检查 |
| 4 | VOFA+ ch5/ch6 为 float 强转 | mode/target 以浮点数形式发送 | VOFA+ 仅支持 float 类型，可接受 |

---

## 附录：完整发送流程速查

### 上位机发指令（控制帧）

```
① 决定模式、目标值、Kp、Kd → 填写 8 字节 payload
② CAN 方式：发到 ID = 0x000 + 电机ID（默认 0x001）
③ UART 方式：
   帧 = [0xAA][0x08][payload][CRC16_CCITT(10B) 小端]
   发到 UART（115200 8N1）
```

### 电机回传数据（状态帧，自动 1kHz）

```
① 电机每 1ms 编码 tx_payload：
     [0..1] = int16(g_pos_rad × 834.4)
     [2..3] = int16(g_spd_rads × 131.07)
     [4..5] = int16(g_vq × 819.175)
     [6..7] = 0x0000
② CAN 方式：ID = 0x100 + 电机ID（默认 0x101），始终发送
③ UART 方式：帧头封装同上，仅 UART 模式发送
④ VOFA+（仅 CAN 模式）：8×float + 帧尾，36 字节
```

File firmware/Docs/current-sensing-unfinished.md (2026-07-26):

---
name: current-sensing-unfinished
description: 电流环 Phase 1 剩余工作 + Phase 2 完整计划（已封存）
metadata:
  type: reference
---

# 电流环未完成部分说明

**封存日期：** 2026-07-26
**原因：** 小电机空载/轻载下，MP6541 SOx 电流检测信噪比不足，放弃电流环。

---

## Phase 1 完成项

| 项目 | 状态 | 说明 |
|---|---|---|
| mp6541_current.h 常量和公式 | ✅ | 换算系数、偏置、增益表 |
| drv_adc.h/c 驱动 | ✅ | DMA CIRCULAR + 快照 + ISR 读接口 |
| foc_math.h/c Clarke+Park | ✅ | 纯数学库，不依赖 ADC |
| Foc.h 电流字段 | ✅ | Ia/Ib/Ic/Ialpha/Ibeta/Id/Iq + current_raw |
| Foc.c FOC_ReadCurrents | ✅ | 读取→Clarke→Park 流水线 |
| main.c ADC_Init + VOFA 通道 | ✅ | 初始化 + 8 通道映射 |
| motor_ctrl.c 调 FOC_ReadCurrents | ✅ | 放在 FOC_UpdateSensor 之后 |

## Phase 1 未完成/有问题的项

| 项目 | 状态 | 详细 |
|---|---|---|
| ADC 采样与 PWM 同步 | ❌ 未解决 | 见 [[current-sensing-retrospective]] v3 分析 |
| TIM3 CC4 中断可靠触发 | ⚠️ 修复中 | CC4E 问题已发现，PWM mode 1 + CCR4=18 方案未验证 |
| 全周期电流波形 | ❌ 未验证 | 只能看到正半周，负半周因采样不同步被削 |
| 编译后实测 + VOFA 验证 | ❌ 未进行 | 代码改完未烧录完整验证 |

## Phase 2 所有内容（完全未动）

以下原本计划在 Phase 1 验证通过后实施：

### 2.1 电流环 PI 控制

- **Foc.h** 加字段: `target_iq`, `CurrPID_D`, `CurrPID_Q`
- **Foc.c** 加 `FOC_CurrCtrl()`: D 轴目标=0，Q 轴目标=target_iq，纯 PI
- **motor_ctrl.c** 改流水线为三环串级: **Pos→Spd→Curr**
- 速度环输出从 Uq 改为 target_iq（电流环算出的 Uq 才不会覆盖）
- **main.c** 加 `FOC_SetCurrPID` 配置

### 2.2 零电流校准

- **drv_adc.c** 实现 `ADC_CalibrateOffset()`: 暂停 DMA → 软件触发轮询 128 次取平均
- **motor_msg.h** 加 `CALIBRATE_CURRENT = 5`
- **led_indicator** 加 `CURRENT_CAL_BLINK` (200ms)
- **can_proto.c** mode 校验范围从 >4 改为 >5

### 2.3 Flash 版本迁移

- `CalibrationData_t` 结构体（含 version 字段）
- 旧版（4B float）→ 新版（含 version 判断）迁移逻辑

### 2.4 力矩模式

- mode=1（原 TORQUE）直接设 `target_iq`，不走速度环

## 封存后代码中可保留的部分

以下与电流相关、但不依赖 ADC 采样硬件的代码，**建议保留**：

- **foc_math.h/c** — Clarke/Park 变换是纯数学，后续无论用何种传感器都需用到
- **Foc.h** 中的 Ia/Ib/Ic/Id/Iq/Ialpha/Ibeta 字段 — 数据结构定义无害
- **FOC_ReadCurrents()** 调用链 — 当前已经被置零，FOC 仍然正常跑

## 恢复条件

如果未来以下任一条件满足，可以接续此工作：
1. **更换更大功率的电机**（额定电流 >1A）
2. **提高母线电压**（12V→24V+，电流信噪比提升）
3. **更换外置电流传感器**（ACS712/INA240 等专用芯片）
4. **PCB 改版**（优化 SOx 走线、加差分放大器）

恢复步骤见 [[current-sensing-retrospective#迁移建议]]。

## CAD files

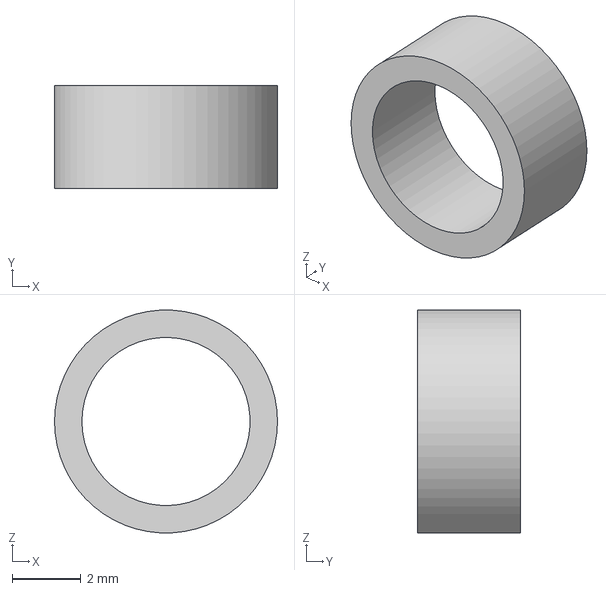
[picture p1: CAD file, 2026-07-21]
mechanical/建模文件/磁环座.step
6.50 x 3.00 x 6.49 mm

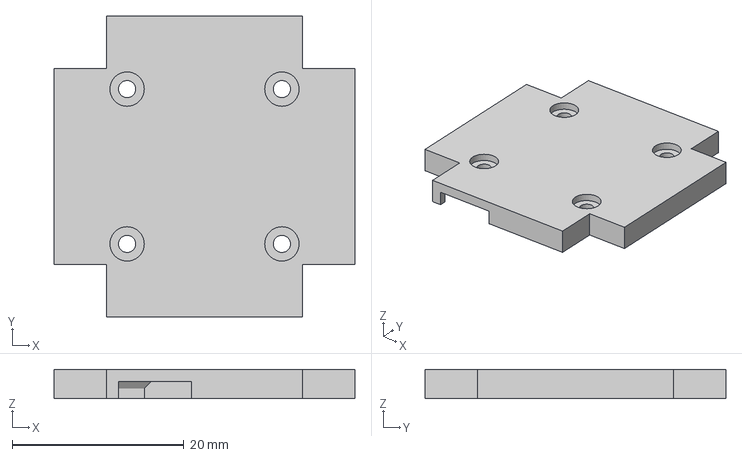
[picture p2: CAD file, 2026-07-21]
mechanical/打印文件/PCB外壳2.3mf
35.0 x 35.0 x 3.40 mm

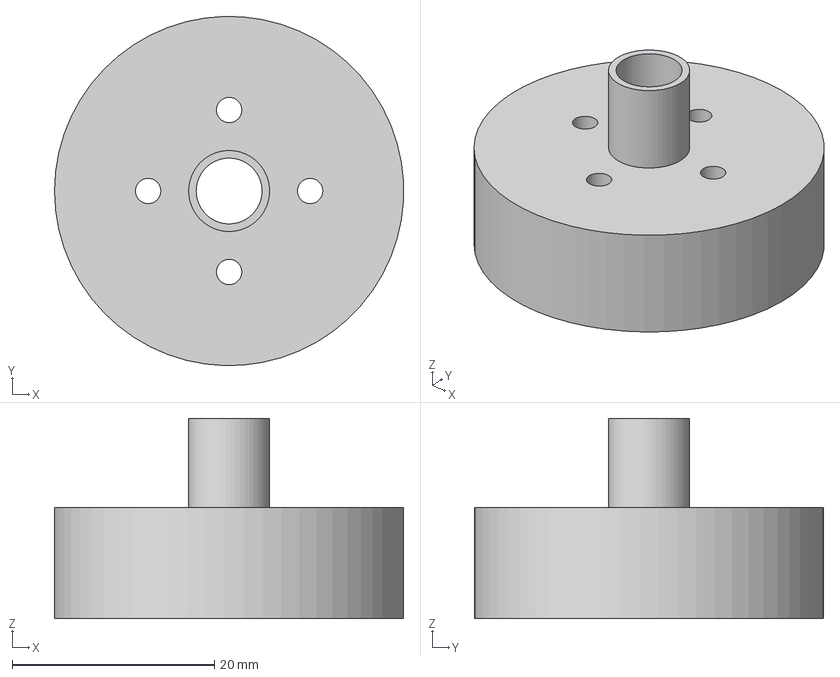
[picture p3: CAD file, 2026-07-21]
mechanical/建模文件/2804电机转子.step
34.5 x 34.5 x 19.8 mm

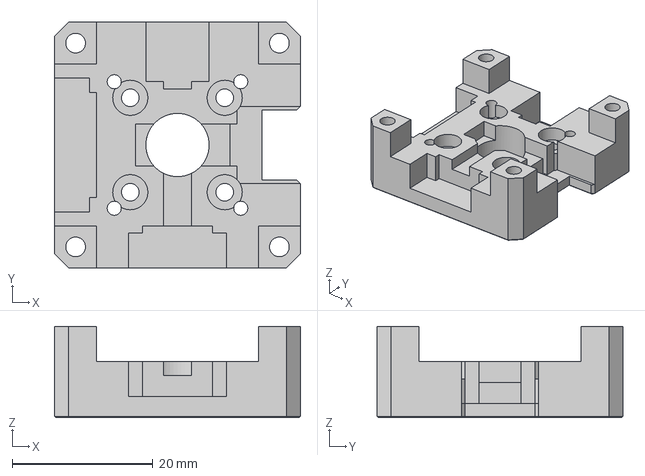
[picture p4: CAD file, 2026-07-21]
mechanical/建模文件/PCB外壳1.step
35.0 x 35.0 x 13.0 mm

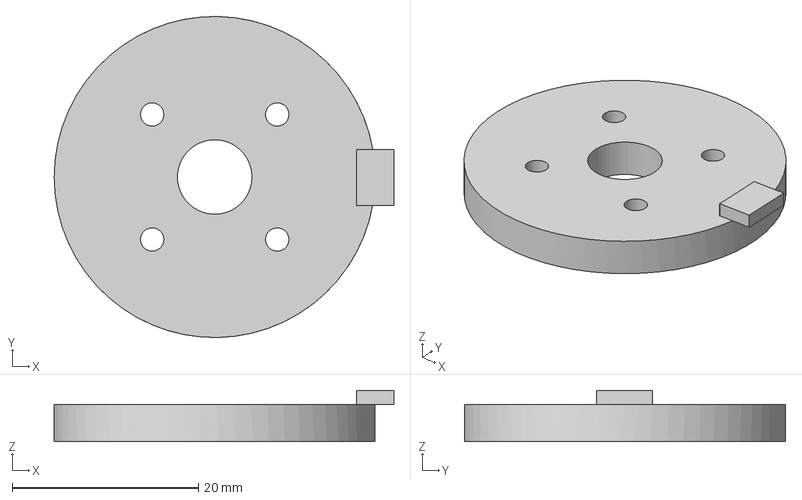
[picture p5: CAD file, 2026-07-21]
mechanical/建模文件/2804电机定子.step
36.5 x 34.5 x 5.50 mm

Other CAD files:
mechanical/打印文件/磁环座.3mf
mechanical/打印文件/PCB外壳1.3mf
mechanical/建模文件/PCB外壳2.step

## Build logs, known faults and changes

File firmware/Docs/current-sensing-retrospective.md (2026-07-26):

---
name: current-sensing-retrospective
description: ADC 电流采样方案试错经验总结（2026-07 已封存）
metadata:
  type: reference
---

# ADC 三相电流采样 — 试错经验总结

**状态：封存** — 该链路已启用但保留代码，供后续参考或硬件升级后复用。

---

## 背景

PicoFOC 使用 **MP6541** 一体式 BLDC 驱动器，其内部集成电流检测放大器（SOA/SOB/SOC 引脚输出），通过外部偏置网络（3.3V→5.1K→SOx→5.1K→GND → 1.65V + 2.55KΩ 等效）将相电流线性映射为电压信号，由 STM32F103C8T6 的 ADC1（PA0/PA1/PA2）采样。

## 问题现象

从"改对"到"改错"到"放弃"，共经历四次架构迭代。以下是每轮的方案、诊断、根因：

---

### v1：HW 触发 → TIM3 TRGO=OC4REF + CCR4=0

**目标：** 每个 PWM 周期在 V0（CNT=0）时刻硬件触发 ADC，DMA 自动搬运。

**CubeMX 配置：**
- TIM3 MasterOutputTrigger = OC4REF
- CH4 = PWM Generation no output, PWM mode 2, CCR4=0
- ADC1 ExternalTriggerConv = Timer 3 Trigger Out, ContinuousConv = DISABLE

**现象：** 三相电流恒为 -7.12A（(0-2048) × 0.003476）。

**根因：** STM32F1 上 TIMx_CH4 的 OC4REF 内部信号受 CC4E 位控制。CubeMX 中 CH4 设为 "PWM Generation no output" → CC4E=0 → OC4REF 被硬件强制拉低，永远无上升沿 → ADC 永远收不到触发 → DMA 缓冲保持 0。

**教训：** 在 F1 系列上，OC4REF 路径需要 CC4E=1 才能工作。即使引脚不输出，也要在 USER CODE 中手动 `TIM3->CCER |= TIM_CCER_CC4E`。

**修复尝试：** 在 tim.c USER CODE 中加 `TIM3->CCER |= TIM_CCER_CC4E` → AVOID（怕被 CubeMX 重置，但其实 USER CODE 不会被覆盖）。

---

### v2：HW 触发 → TIM3 TRGO=Update

**目标：** 改用 Update Event 触发 ADC（简单粗暴）。

**CubeMX 配置：**
- TIM3 MasterOutputTrigger = Update
- ADC1 ExternalTriggerConv = Timer 3 Trigger Out

**现象：** 能采到正弦波，但：
1. 只有上半周（正半周），负半周被削
2. 三角波变形 + 周期性 dropout（采几周期→全 0→再采到）
3. Id/Iq 形态倒是对的（正弦→Clarke→Park 后信息仍在）

**根因：** 中心对齐 PWM 模式下，Update Event 在 V0（CNT=0）和 V7（CNT=1799）各触发一次 → ADC 以 40kHz 双触发率运行。V7 时刻三个上管导通，SOx 反映的是高侧电流，偏置不同，且电机续流路径不同 → 读数不可用。DMA 缓冲区交替混入 V0 有效值和 V7 无效值 → FOC 1kHz 快照时随机读到 V0/V7 数据 → 波形畸变。

**教训：** 对于三相半桥驱动，电流采样只能在 V0（零矢量，低侧续流）时刻有效。任何在 V7 的采样都会读到错误值。Update Event 双触发无法被 F1 硬件过滤，必须避免。

---

### v3：ADC 连续自由转换 + DMA CIRCULAR + TIM3 CC4 中断

**目标：** ADC 完全自由连续转换（~98kHz，3 通道每 10.5µs 扫一轮），DMA CIRCULAR 持续更新。TIM3 CH4 在 V0 触发 CC4 中断，ISR 中读取 DMA 最新值。

**CubeMX 配置：**
- ADC1 ContinuousConvMode = ENABLE, ExternalTrigConv = ADC_SOFTWARE_START
- TIM3 MasterOutputTrigger = RESET（不参与 ADC 触发）
- CH4 = PWM Generation no output, PWM mode 2, CCR4=0（只用 CC4 中断做 V0 同步）

**现象：**
- 直接读 DMA 缓冲（`s_adc_dma_buf`）：能看到三相 ~120° 正弦波，但只有 2048 以上（正半周），负半周被削
- 断电能看到下降到 2048 以下，但正常运行负半周几乎看不到
- Id/Iq 仍有明显正弦成分

**根因（诊断过程）：**
1. 确认 DMA 缓冲区通过 VOFA+ ch5/6/7 原值读出 → 数据更新、波形存在 → **ADC + DMA 链路正常**
2. 用快照（`ADC_TakeSnapshot` 关中断拷贝） → 结果跟直读一样 → **竞态不是问题**
3. `Motor.current_raw` 一直为 0 → ISR 没执行 → 发现 **CC4E=0 导致 CC4IF 不置位** → 加 `TIM3->CCER |= TIM_CCER_CC4E`
4. CC4E 加上后仍为 0 → 怀疑 **CCR4=0 与更新事件竞争** → 改用 PWM mode 1 + CCR4=18（~1% 占空比）

**根本问题（未解决）：**
ADC 虽然是"自由连续转换"，**但它与 PWM 不同步**。DMA 缓冲区中存储的是最近一次完成的 ADC 扫描，而该扫描可能发生在 PWM 周期的任意时刻。TIM3 CC4 在 V0 附近触发并读取 DMA，读到的是**上一个任意时刻完成的转换结果**——可能来自 V0（偏置正确），也可能来自 V7 附近（电流换路、偏置异常）。因此正半周（V0 附近电流大时偶然对应 V0 采样）可见，负半周不可见。

**教训：**
- 在 STM32F1 上，**连续自由转换 + 定时中断读 DMA** 无法保证采样时刻与 PWM 同步
- 要真正同步，必须用硬件触发 ADC + DMA（回到 v1 思路）——但这需要正确配置 CC4E
- 或者用两个定时器：TIM3 发 PWM，TIM3_CH4 OC4REF 触发 ADC（需要 CC4E=1）
- 另一个方向：用 TIM1（20kHz 中断）触发软件 ADC 启动——但软件触发有抖动

---

### v4：PWM mode 1 + CCR4=18（尝试修复 v3）

**目标：** 用非零 CCR4 避开 CNT=0 的竞争，让 CC4 中断可靠触发。

**配置：** TIM3 CH4 在 CubeMX 初始化后手动覆盖：
- `TIM3->CCMR2 = (old & 0x8FFF) | 0x6000`  → PWM mode 1
- `TIM3->CCR4 = 18`

**结果：** 未验证（在调试中发现并修复 CC4E 后，用户决定放弃电流采样）。

**理论分析：** 即使 CC4 中断可靠触发，v3 的根本问题（ADC 采样与 PWM 不同步）仍然存在。因此这条路线本质上也无法解决波形削波问题。

**结论：** 需要同时做两件事——① CC4E=1 让中断能触，② 回到 HW 触发 ADC（TIM3 TRGO=OC4REF + CC4E=1），让 ADC 在 V0 时刻被硬件启动采样，才能保证同步。

---

## 硬件限制分析

在调试过程中确认的小电机空载/轻载电流特征：
- 小电机（如本项目的 7 对极微型 BLDC）在空载/轻载时，相电流幅度很有限
- MP6541 SOx 输出电压摆幅小，信噪比差
- 偏置网络（1.65V）漂移 + PCB 布局噪声 + ADC 量化噪声 → 有效分辨率不足
- 电流的正弦形态虽然存在，但幅值太小 → 即使在 VOFA 上能看到半周，也无法做可靠的控制反馈

## 关键经验总结

| 方向 | 结论 |
|---|---|
| ADC 触发 | F1 上用 OC4REF 触发 ADC，必须在 USER CODE 中手动 CC4E=1 |
| Update Event 触发 | 中心对齐模式下 V0+V7 双触发，不能使用 |
| 连续转换+ISR读 | 采样时刻与 PWM 不同步，V7 附近读数错误 |
| CC4 中断 | CCR4=0 可能与更新事件竞争导致不触发，建议用非零值 |
| MP6541 精度 | 适合大电流（>1A），微小型电机空载不适用 |
| 调试手段 | VOFA+ 直接发 DMA 原始值 / 快照值 / 重构值，逐级确认比猜测效率高 |

## 迁移建议

如果后续硬件升级（更大电机 / 更高母线电压 / 外部电流传感器），恢复电流环的步骤：
1. 将 CubeMX 回复：ADC1 ExternalTriggerConv = Timer 3 Trigger Out, ContinuousConv = DISABLE
2. tim.c USER CODE 加 `TIM3->CCER |= TIM_CCER_CC4E`
3. TIM3 MasterOutputTrigger = OC4REF, CCR4=0, PWM mode 2
4. 重新使能 `main.c` 中的 `ADC_Init()`、CC4 中断配置、CH4 reconfig
5. 验证：VOFA 看 `current_raw` 是否出现完整正负正弦波
6. 然后做零电流校准、电流环 PI 调参

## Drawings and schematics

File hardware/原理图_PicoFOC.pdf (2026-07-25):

# VDD_2 36 PA14 37 PA15 38 PB3 39 PB4 40 PB5 41 PB6 42 PB7 43 BOOT0 44 PB8 45 PB9 46

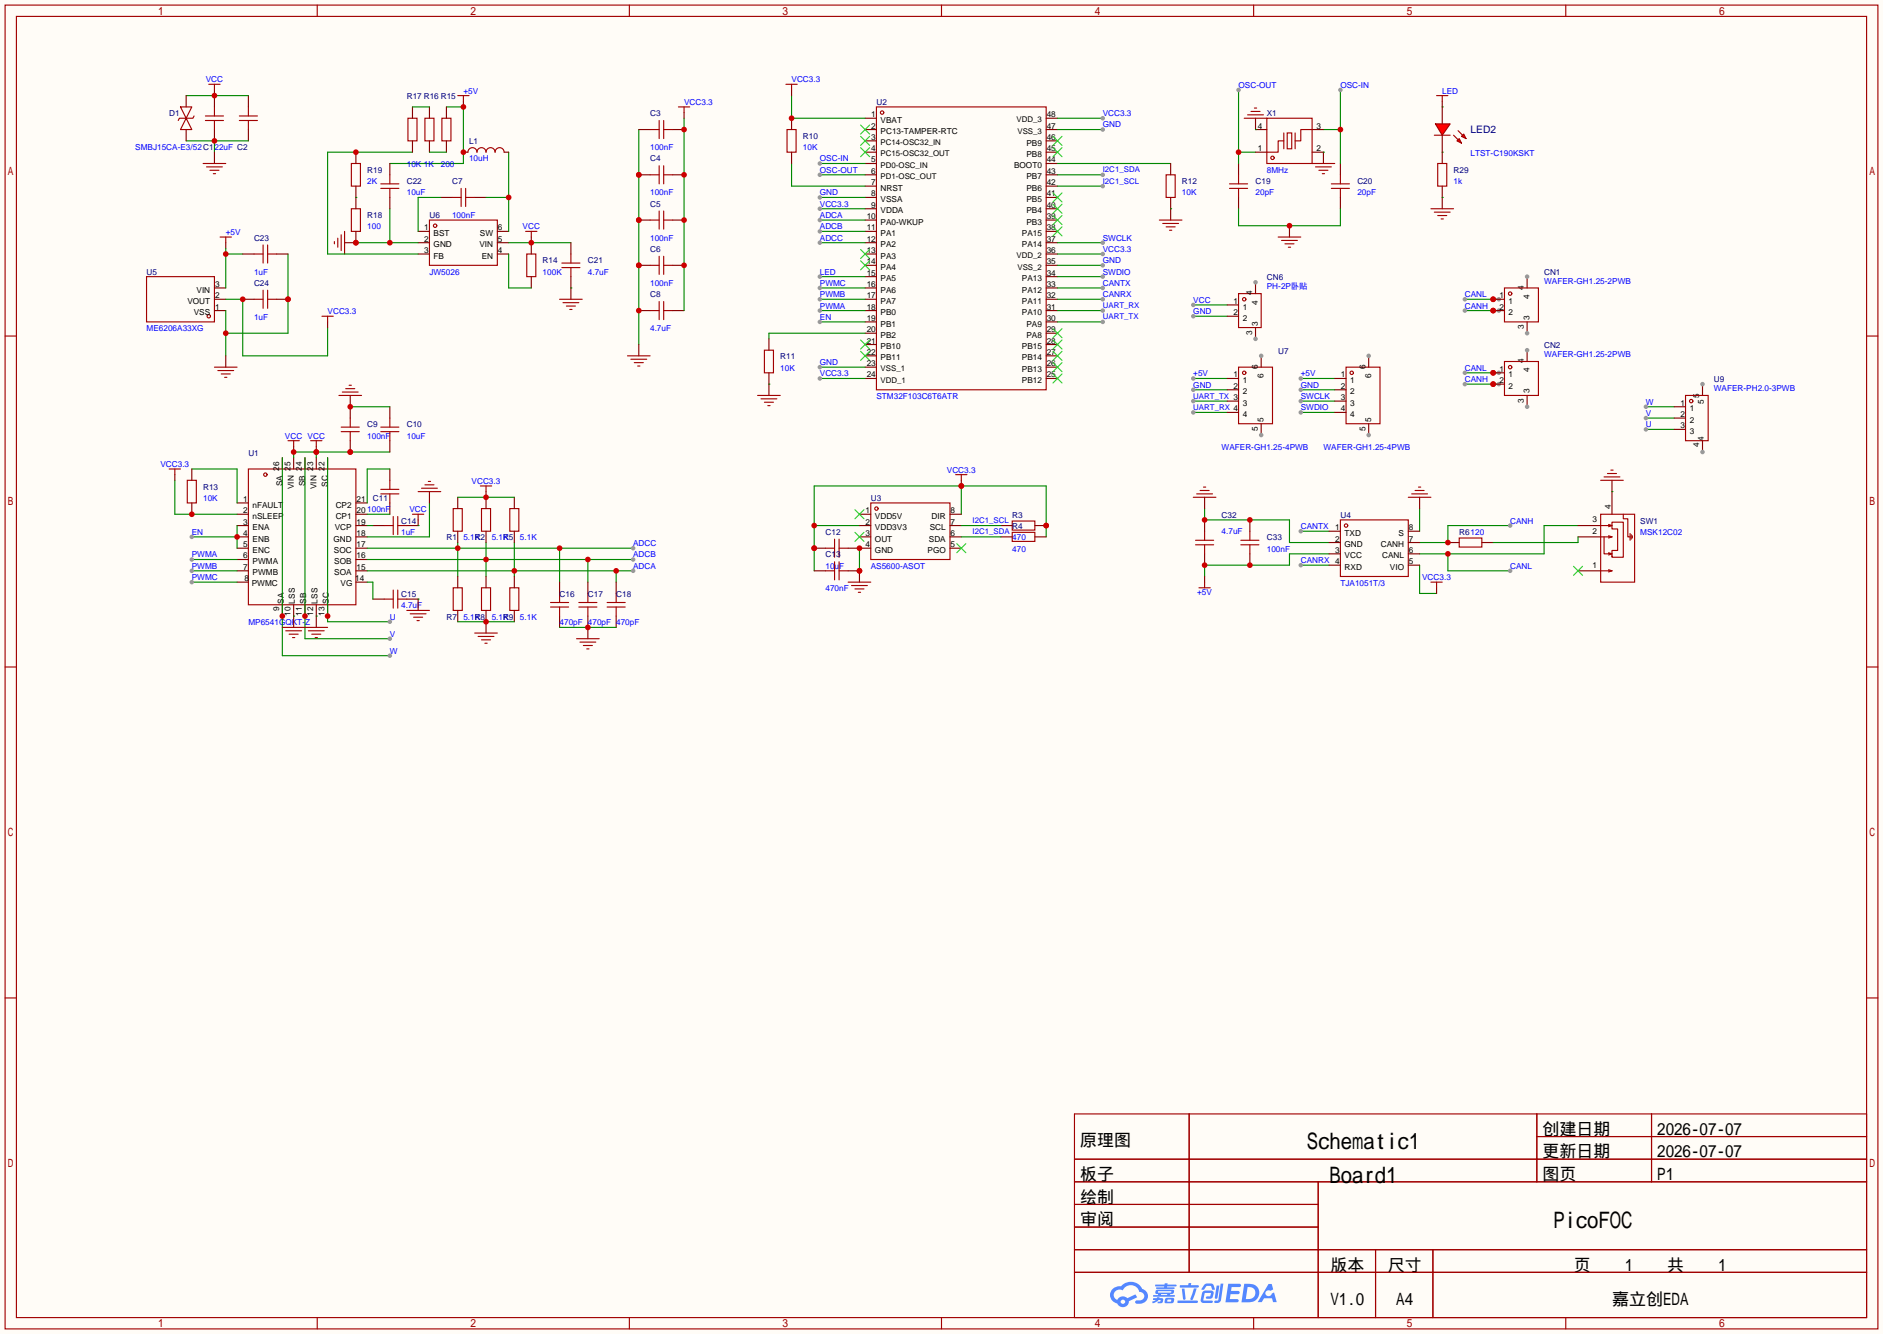
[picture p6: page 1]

VG 14 SOA 15 SOB 16 SOC 17 GND 18 VCP 19 CP1 20 CP2 21

原理图 | Schematic1 | 创建日期 | 2026-07-07

更新日期 | 2026-07-07

板子 | Board1 | 图页 | P1
绘制 | | PicoFOC
审阅

V1.0 | A4 | 嘉立创EDA

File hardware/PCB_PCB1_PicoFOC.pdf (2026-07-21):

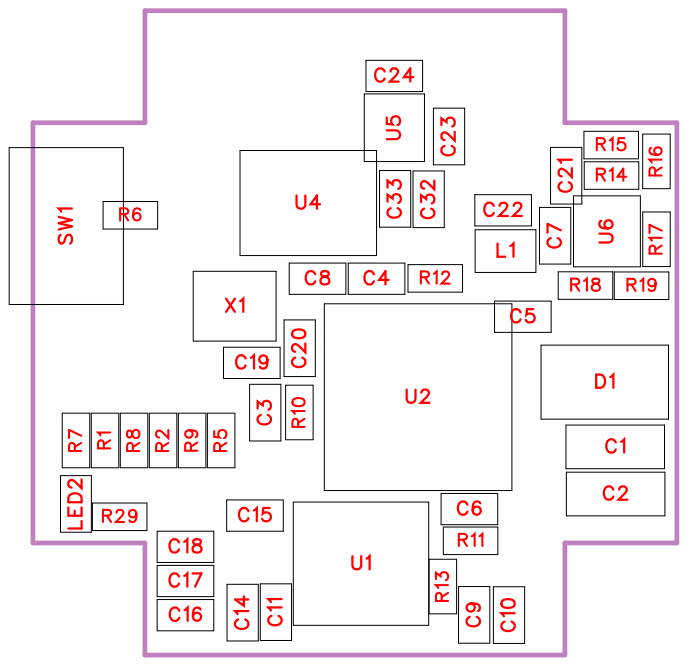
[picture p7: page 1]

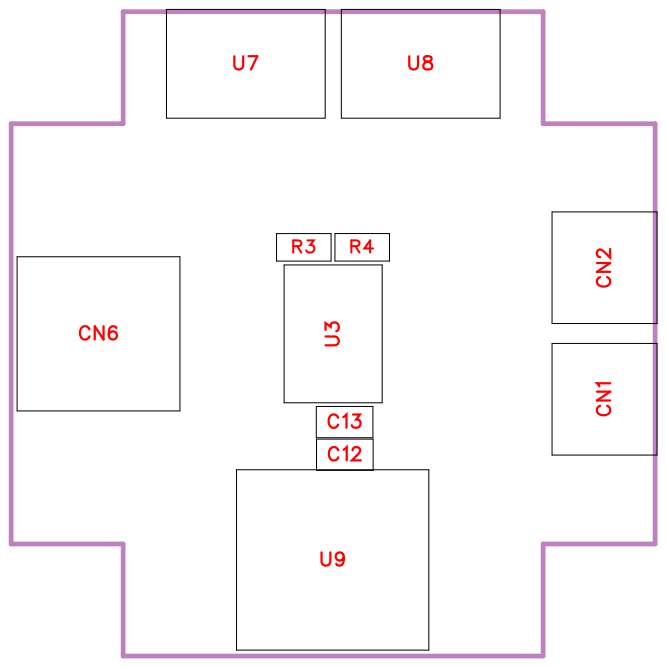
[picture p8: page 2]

No. | Quantity | Comment | Designator | Footprint | Value | Manufacturer Part | Manufacturer | Supplier Part | Supplier
1 | 2 | 22uF | C1,C2 | C1206 | 22uF | HGC1206R5 106K500NSP J | Chinocera(华 瓷) | | LCSC
2 | 5 | 100nF | C3,C4,C5,C6,C33 | C0603 | 100nF | CC0603KRX 7R9BB104 | YAGEO(国巨 ) | C14663 | LCSC
3 | 3 | 100nF | C7,C9,C11 | C0603 | 100nF
4 | 1 | 4.7uF | C8 | C0603 | 4.7uF | CL10A475K O8NNNC | SAMSUNG( 三星) | C19666 | LCSC
5 | 3 | 10uF | C10,C12,C22 | C0603 | 10uF
6 | 1 | 470nF | C13 | C0603 | 470nF
7 | 1 | 1uF | C14 | C0603 | 1uF
8 | 2 | 4.7uF | C15,C21 | C0603 | 4.7uF
9 | 3 | 470pF | C16,C17,C18 | C0603 | 470pF
10 | 2 | 20pF | C19,C20 | C0603 | 20pF | 0603CG200F 500NT | FH(风华) | C165732 | LCSC
11 | 2 | 1uF | C23,C24 | C0603 | 1uF | CL10A105KB 8NNNC | SAMSUNG( 三星) | C15849 | LCSC
12 | 1 | 4.7uF | C32 | C0603 | 4.7uF | GRM188R6Y A475KE15D | muRata(村田 ) | C162274 | LCSC
13 | 2 | WAFER-GH1 .25-2PWB | CN1,CN2 | CONN-TH_2 P-P1.25_XU NPU_WAFE R-GH1.25-2P WB | | WAFER-GH1 .25-2PWB | XUNPU(讯普 ) | C3029377 | LCSC
14 | 1 | PH-2P卧贴 | CN6 | CONN-SMD_ 2P-P2.00_P H2.0-SPWB | | PH-2P卧贴 | BOOMELE( 博穆精密) | C47647 | LCSC
15 | 1 | SMBJ15CA-E3/52 | D1 | SMB_L4.6-W 3.6-LS5.3-BI | | SMBJ15CA-E3/52 | VISHAY(威世 ) | C435933 | LCSC
16 | 1 | 10uH | L1 | IND-SMD_L2 .5-W2.0 | 10uH | FTC252012S 100MBCA | cjiang(长江微 电) | C5832376 | LCSC
17 | 1 | LTST-C190K SKT | LED2 | LED0603-RD | | LTST-C190K SKT | LITEON(光宝 ) | C125095 | LCSC
18 | 6 | 5.1K | R1,R2,R5,R7,R8,R9 | R0603 | 5.1K
19 | 2 | 470 | R3,R4 | R0603 | 470
20 | 1 | 120 | R6 | R0603 | 120 | 0603WAF12 00T5E | UNI-ROYAL( 厚声) | C22787 | LCSC
21 | 5 | 10K | R10,R11,R12,R13,R17 | R0603 | 10K
22 | 1 | 100K | R14 | R0603 | 100K
23 | 1 | 200 | R15 | R0603 | 200
24 | 1 | 1K | R16 | R0603 | 1K
25 | 1 | 100 | R18 | R0603 | 100
26 | 1 | 2K | R19 | R0603 | 2K
27 | 1 | 1k | R29 | R0603 | 1k | 0603WAF10 01T5E | UNI-ROYAL( 厚声) | C21190 | LCSC

28 | 1 | MSK12C02 | SW1 | SW-TH_MSK 12C02 | | MSK12C02 | SHOU HAN(首韩 ) | C431540 | LCSC
29 | 1 | MP6541GQK T-Z | U1 | QFN-26_L6.0 -W6.0-P0.65-TL_MP6541 | | MP6541GQK T-Z | MPS(芯源 ) | C19089145 | LCSC
30 | 1 | STM32F103 C6T6ATR | U2 | LQFP-48_L7. 0-W7.0-P0.5 0-LS9.0-BL | | STM32F103 C6T6ATR | ST(意法半导 体) | C2053946 | LCSC
31 | 1 | AS5600-ASO T | U3 | SOIC-8_L5.0 -W4.0-P1.27-LS6.0-BL | | AS5600-ASO T | ams(艾迈斯 ) 半导体 | C499458 | LCSC
32 | 1 | TJA1051T/3 | U4 | SOP-8_L4.9-W3.9-P1.27-LS6.0-BL-1 | | TJA1051T/3 | Tokmas(托克 ) 马斯 | C5342108 | LCSC
33 | 1 | ME6206A33 XG | U5 | SOT-23-3_L2 .9-W1.6-P1.9 0-LS2.8-BR | | ME6206A33 XG | MICRONE( 南 ) 京微盟 | C161345 | LCSC
34 | 1 | JW5026 | U6 | SOT-23-6_L2 .9-W1.6-P0.9 5-LS2.8-BR | | JW5026 | Joulwatt(杰华 特) | C185109 | LCSC
35 | 2 | WAFER-GH1 .25-4PWB | U7,U8 | CONN-SMD_ 4P-P1.25_X UNPU_WAF ER-GH1.25-4 PWB | | WAFER-GH1 .25-4PWB | XUNPU(讯普 ) | C3029379 | LCSC
36 | 1 | WAFER-PH2 .0-3PWB | U9 | CONN-SMD_ 3P-P2.00_X UNPU_WAF ER-PH2.0-3P WB | | WAFER-PH2 .0-3PWB | XUNPU(讯普 ) | C3029441 | LCSC
37 | 1 | 8MHz | X1 | CRYSTAL-S MD_4P-L3.2-W2.5-BL | 8MHz | X32258MSB 4SI | YXC(扬兴晶 振) | C2682774 | LCSC

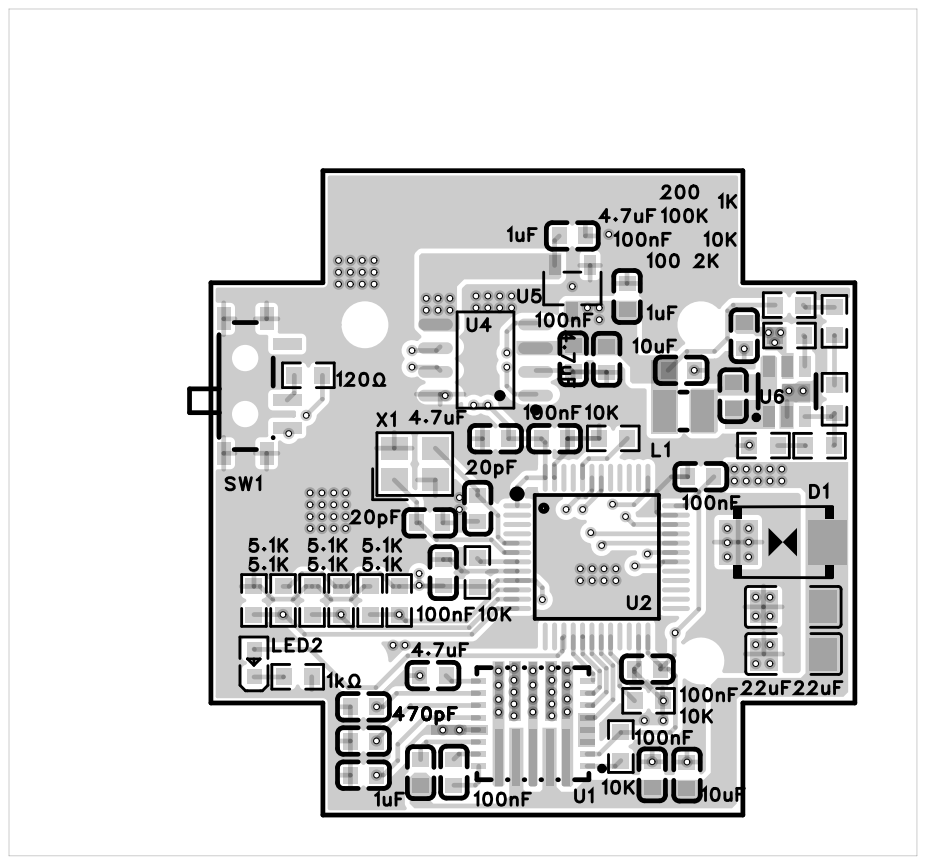
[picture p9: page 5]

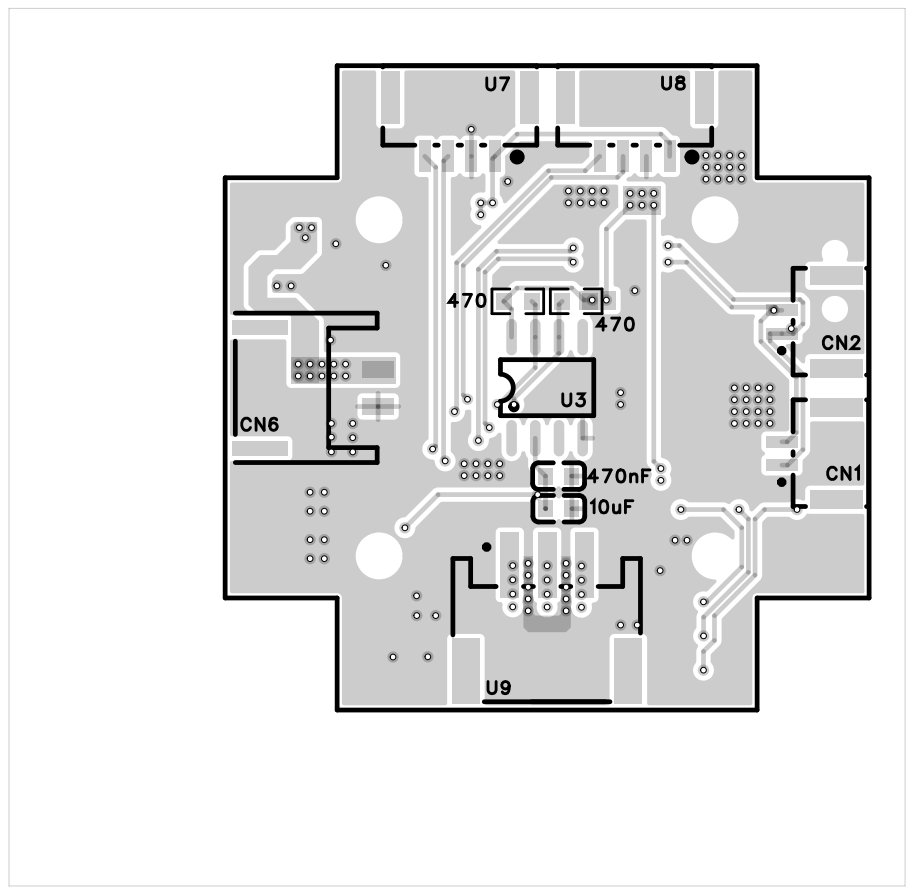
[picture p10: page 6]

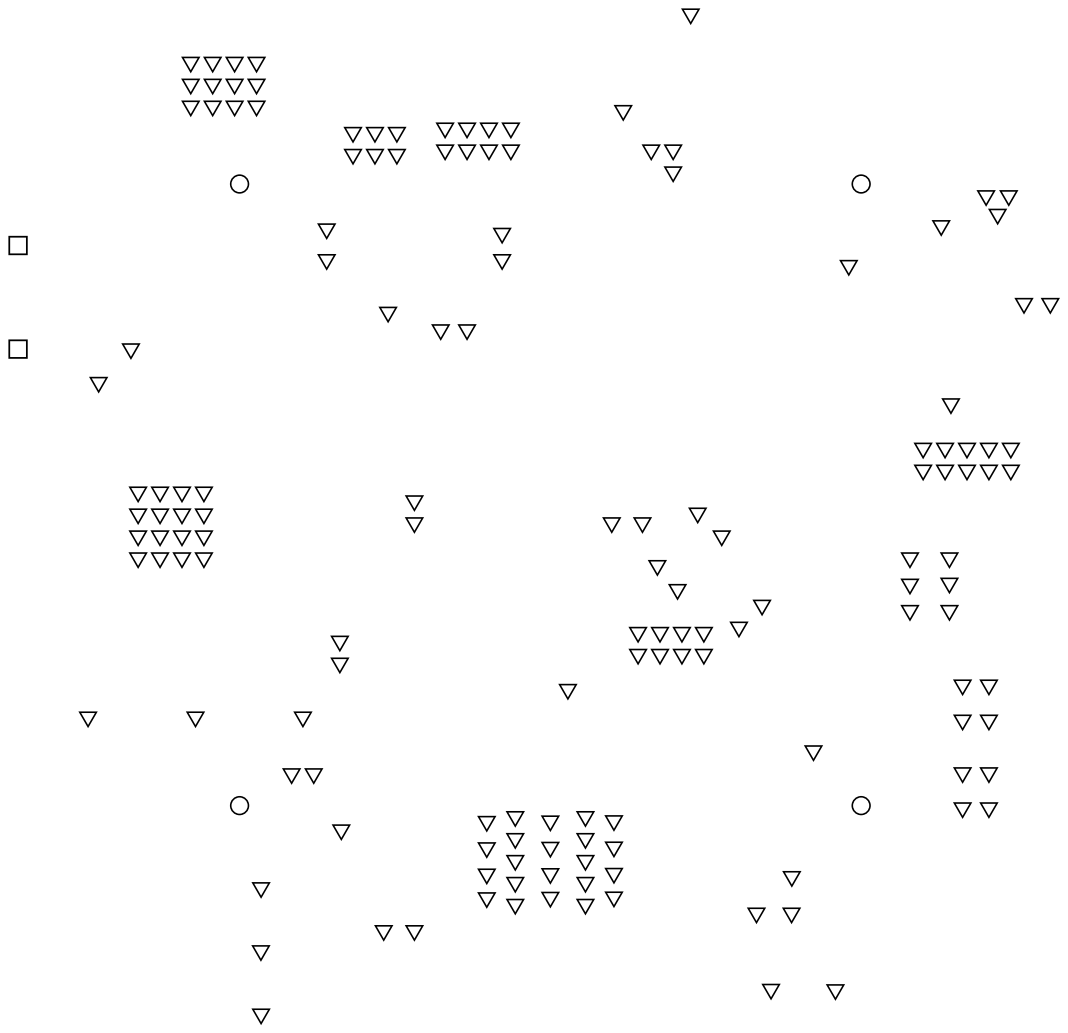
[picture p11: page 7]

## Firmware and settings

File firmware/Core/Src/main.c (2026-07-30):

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
/* Includes ------------------------------------------------------------------*/
#include "main.h"
#include "adc.h"
#include "can.h"
#include "dma.h"
#include "i2c.h"
#include "tim.h"
#include "usart.h"
#include "gpio.h"

/* USER CODE BEGIN Includes */
#include "Foc.h"
#include "drv_tim.h"
#include "drv_can.h"
#include "can_proto.h"
#include "motor_msg.h"
#include "uart_proto.h"
#include "motor_ctrl.h"
#include "angle_as5600.h"
#include "pwm_3phase.h"
#include "motor_config.h"
#include "flash_storage.h"
#include "led_indicator.h"
/* 差分法观测器（角度直通，速度差分） */
/* #include "observer_diff.h" */
/* 龙伯格观测器（二阶模型，同时滤波位置和速度） */
#include "observer_luenberger.h"
/* USER CODE END Includes */

/* USER CODE BEGIN PD */

/** @brief FOC 控制频率 (Hz) —— 观测器和 FOC 共用的唯一频率源头 */
#define FOC_RATE_HZ  1000.0f

/* USER CODE END PD */


/* USER CODE BEGIN PV */
float vofa_message[8];
/* USER CODE END PV */

void SystemClock_Config(void);
/* USER CODE BEGIN PFP */
static void IWDG_Init(void);
static void VOFA_SendDebug(void);
/* USER CODE END PFP */

/**
  * @brief  The application entry point.
  * @retval int
  */
int main(void)
{

  /* MCU Configuration--------------------------------------------------------*/

  /* Reset of all peripherals, Initializes the Flash interface and the Systick. */
  HAL_Init();

  /* Configure the system clock */
  SystemClock_Config();

  /* Initialize all configured peripherals */
  MX_GPIO_Init();
  MX_DMA_Init();
  MX_I2C1_Init();
  MX_TIM3_Init();
  MX_TIM1_Init();
  MX_CAN_Init();
  MX_USART1_UART_Init();
  MX_ADC1_Init();
  /* USER CODE BEGIN 2 */

  /* ================================================================
   *  第 1 步：电机硬件配置
   *
   *  MotorConfig_t 集中管理极对数、母线电压、控制频率，
   *  同时注入 FOC 控制器和 PWM 驱动，消除重复配置。
   * ================================================================ */
  MotorConfig_t cfg = {
      .pole_pairs  = 7,
      .bus_voltage = 12.0f,
      .rate_hz     = FOC_RATE_HZ,
  };

  /* ================================================================
   *  第 2 步：创建硬件接口实例
   *
   *  AS5600_Create()  →  填充 AngleSensor_t，封装 I2C
   *  PWM3Phase_Create() → 填充 PwmOutput_t，封装 TIM3 PWM
   *                      set_duty 接收归一化值，不再需要母线电压
   *
   *  换编码器 / 换 PWM 方案 = 只改下面两行
   * ================================================================ */
  HAL_Delay(100);
  AngleSensor_t sensor = AS5600_Create(&hi2c1);
  PwmOutput_t   pwm    = PWM3Phase_Create(&htim3);
  HAL_Delay(100);

  /* ================================================================
   *  第 3 步：创建非易失存储接口 + 观测器 + 初始化 FOC 控制器
   *
   *  FlashStorage_Create 封装 STM32 Flash 擦写，
   *  换其它介质（EEPROM/FRAM）只需换一个工厂函数。
   *
   *  观测器（Observer）负责将原始角度转为滤波后角度和估计速度。
   *  默认用差分法（ObserverDiff_Create），换龙伯格只需：
   *     ObserverLuenberger_Config obs_cfg = { .rate_hz = FOC_RATE_HZ, ... };
   *     Observer_t angle_obs = ObserverLuenberger_Create(&obs_cfg);
   *
   *  FOC_Init(&Motor, &sensor, &pwm, &cfg, &flash, &angle_obs)
   *  所有电机参数通过 cfg 传入，存储接口通过 flash 传入。
   *
   *  ⚠ 频率改一个地方就够了：改 #define FOC_RATE_HZ，观测器和 FOC 都同步。
   * ================================================================ */
  NvStorage_t flash = FlashStorage_Create(0x0800FC00, 0xF0C0F0C0, 1024);

  /* 创建角度/速度观测器（使用龙伯格观测器，同时滤波位置和速度） */
  ObserverLuenberger_Config obs_cfg = {
      .rate_hz   = FOC_RATE_HZ,
      .l1        = 0.5f,        /* 位置校正增益——提高跟踪速度，控制滞后在 ~2ms */
      .l2        = 1.0f,        /* 速度校正增益——轻柔估计，不给速度环注入抖动 */
      .speed_max = 10000.0f,    /* 速度限幅 (rpm) */
  };
  Observer_t angle_obs = ObserverLuenberger_Create(&obs_cfg);

  FOC_Init(&Motor, &sensor, &pwm, &cfg, &flash, &angle_obs);

  /* ================================================================
   *  第 4 步：设置 PID 参数
   *
   *  PID 已做时间归一化（integral *= dt），ki 值自动适配频率。
   *  你传入原来的 ki 值即可，效果不变。
   *
   *  原代码对照：
   *    pid_controller_create(&FOC_1.FOC_S_PID, 0.01, 0.004, 0, 1000, 1000, 6);
   *    → FOC_SetSpdPID(&Motor, 0.01, 0.004, 0, 6);
   *
   *    pid_controller_create(&FOC_1.FOC_P_PID, 5, 0, 0, 1000, 2000, 2000);
   *    → FOC_SetPosPID(&Motor, 5, 0, 0, 2000);
   * ================================================================ */
  FOC_SetSpdPID(&Motor, 0.1f,   0.004f, 0.0f, 6.0f);     /* 串级速度环（位置环内环） — Kp 从 0.01→0.1，解决稳态附近 P 项太弱靠积分慢爬 */
  FOC_SetPosPID(&Motor, 5.0f,   0.0f,   0.0f, 2000.0f);   /* 位置环 PD */
  FOC_SetSpdExtPID(&Motor, 0.05f, 0.01f, 0.0f, 12.0f);    /* 独立速度环 PI（速度模式专用） */

  /* ================================================================
   *  第 5 步：初始化驱动层 + 协议层
   *
   *  【初始化顺序很重要！】
   *  CAN_Init()       : 配置滤波器 + 启动 CAN 硬件
   *  MotorMsg_Init()  : 先初始化消息总线（消息总线准备就绪前，通信回调不能写它）
   *  CANProto_Init()  : 注册 CAN 回调（收到 CAN 帧 → 调 MotorMsg_OnFrameReceived）
   *  UARTProto_Init() : 使能 UART RX 中断（收到 UART 帧 → 调 MotorMsg_OnFrameReceived）
   *  TIM_Init()       : 最后启动时基中断（TIM1 硬件 20kHz → 软件 20 分频 → 1kHz FOC 循环）
   * ================================================================ */
  CAN_Init();
  HAL_Delay(100);
  MotorMsg_Init();    /* 先初始化消息总线 */
  CANProto_Init(1);    /* 再注册 CAN 回调，电机ID=1 → RX=0x001 TX=0x101 */
  UARTProto_Init();   /* 再使能 UART 接收 */
  TIM_Init();

  /* LED 初始状态：待机心跳（满亮度闪烁），覆盖默认的常灭 */
  LED_SetPattern(LED_PATTERN_HEARTBEAT);
  LED_SetBrightness(100);

  /* ================================================================
   *  第 6 步：注册控制回调
   *
   *  Motor_Loop()  : TIM1 中断 → 1kHz FOC 流水线
   * ================================================================ */
  TIM_RegisterCallback(Motor_Loop);

  /* ---- 启动独立看门狗（~2s 超时，主循环 + Motor_Loop 双重喂狗） ---- */
  IWDG_Init();

  /* USER CODE END 2 */

  /* Infinite loop */
  /* USER CODE BEGIN WHILE */
  while (1)
  {
      IWDG_REFRESH();   /* 喂独立看门狗 */
      VOFA_SendDebug();
    /* USER CODE END WHILE */

    /* USER CODE BEGIN 3 */
  }
  /* USER CODE END 3 */
}

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
/* USER CODE BEGIN 4 */

/**
 * @brief  初始化独立看门狗（IWDG）
 *
 * 使用 LSI ~40kHz 时钟源，预分频 /256 → ~156.25 Hz。
 * 重装载值 312 → 超时 ≈ 312 / 156.25 ≈ 2.0s。
 *
 * 配置采用寄存器直接操作，不依赖 HAL_IWDG 模块，
 * 与 IWDG_REFRESH() 宏保持一致的风格。
 *
 * 调用时机：main() 中所有外设初始化完成后、主循环开始前。
 */
static void IWDG_Init(void)
{
    /* 开启 LSI 时钟（复位后默认关闭，需先启动再等就绪） */
    RCC->CSR |= RCC_CSR_LSION;
    while (!(RCC->CSR & RCC_CSR_LSIRDY));

    /* 解锁 PR / RLR 寄存器写保护 */
    IWDG->KR = 0x5555U;

    /* 预分频器 = /256: 40kHz / 256 = 156.25 Hz */
    IWDG->PR = 0x06U;

    /* 重装载 = 312: 312 / 156.25 ≈ 2.0s */
    IWDG->RLR = 0x0138U;

    /* 刷新计数器 */
    IWDG->KR = 0xAAAAU;

    /* 软件启动 IWDG（LSI 已就绪，启动后立即开始递减计数） */
    IWDG->KR = 0xCCCCU;
}

/**
 * @brief  通过 UART1 发送调试数据到 VOFA+ 串口示波器
 *
 * 帧格式（just-float 引擎）：
 *   8 × float (32 bytes) + 4-byte tail {0x00,0x00,0x80,0x7f}
 *
 * 触发条件：仅 CAN 模式下发送（由 MotorMsg_IsCANMode 判定）
 *   CAN 模式：VOFA+ 全速发送（UART 自定义协议停发，带宽空出）
 *   UART 模式：VOFA+ 停发（UART 自定义协议 1kHz 跑满）
 *
 * 通道映射：
 *   ch0 = 机械角度 (deg)        ch1 = 目标角度 (deg)
 *   ch2 = 转速 (rpm)            ch3 = 目标转速 (rpm)
 *   ch4 = Uq 电压 (V)           ch5 = 运行模式 (int)
 *   ch6 = 最近指令目标值          ch7 = 保留
 */
static void VOFA_SendDebug(void)
{
    /* 仅 CAN 模式下发送 VOFA+（UART 模式下让带宽给自定义协议 1kHz） */
    if (!MotorMsg_IsCANMode())
        return;

    vofa_message[0] = Motor.mech_angle;           /* ch0：机械角度 (deg)        */
    vofa_message[1] = Motor.target_angle;         /* ch1：目标角度 (deg)        */
    vofa_message[2] = Motor.speed;                /* ch2：转速 (rpm)            */
    vofa_message[3] = Motor.target_speed;         /* ch3：目标转速 (rpm)        */
    vofa_message[4] = Motor.Uq;                   /* ch4：Uq 输出电压 (V)       */
    vofa_message[5] = (float)MotorMsg_GetLastMode(); /* ch5：运行模式 (int)      */
    vofa_message[6] = MotorMsg_GetLastTarget();   /* ch6：最近指令目标值         */
    vofa_message[7] = 0.0f;                       /* ch7：保留                  */

    UARTProto_SendVOFA(vofa_message, 8);
}

/* USER CODE END 4 */
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


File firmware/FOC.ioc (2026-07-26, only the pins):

Mcu.UserName=STM32F103C8Tx
PA0-WKUP.Signal=ADCx_IN0
PA1.Signal=ADCx_IN1
PA10.Signal=USART1_RX
PA11.Signal=CAN_RX
PA12.Signal=CAN_TX
PA13.Signal=SYS_JTMS-SWDIO
PA14.Signal=SYS_JTCK-SWCLK
PA2.Signal=ADCx_IN2
PA5.Signal=GPIO_Output
PA6.Signal=S_TIM3_CH1
PA7.Signal=S_TIM3_CH2
PA9.Signal=USART1_TX
PB0.Signal=S_TIM3_CH3
PB1.Signal=GPIO_Output
PB6.Signal=I2C1_SCL
PB7.Signal=I2C1_SDA
PD0-OSC_IN.Signal=RCC_OSC_IN
PD1-OSC_OUT.Signal=RCC_OSC_OUT

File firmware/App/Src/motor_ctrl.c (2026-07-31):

/**
 * @file    motor_ctrl.c
 * @brief   电机控制任务调度 —— 抽象指令分发 + FOC 流水线
 *
 * SPDX-License-Identifier: MIT
 * Copyright (c) 2024 The FOC Firmware Contributors
 *
 * 由 TIM1 周期中断回调触发，运行频率 1 kHz。
 *
 * 与通信介质解耦：通过 motor_msg.h 统一接口收发指令/状态，
 * 不再直接依赖 can_proto 或 uart_proto。
 *
 * 每轮控制流程：
 *   1. 轮询消息总线获取最新指令 → 解析运行模式与目标值
 *   2. 处理模式切换（待机 ↔ 运行，使能 / 关断驱动芯片）
 *   3. 按当前模式执行对应控制策略
 *   4. 运行 FOC 流水线（传感器 → 控制环 → SVPWM → 输出）
 *   5. 更新状态 → 触发所有通道回传（1 kHz）
 */

#include "motor_ctrl.h"
#include "Foc.h"
#include "motor_msg.h"
#include "data_process.h"
#include "drv_tim.h"
#include "led_indicator.h"
#include "main.h"

/* SPEED_LIMIT_RPM 定义于 motor_config.h —— 所有模块共享 */

void Motor_Loop(void)
{
    static MotorMode_t   g_mode     = MOTOR_MODE_STANDBY;    /**< 当前运行模式 */
    static uint16_t      g_comms_timeout = 0;                /**< 通信超时计数器 */
    static float         g_speed_desired = 0.0f;             /**< 速度指令目标（rpm），target_speed 斜坡逼近 */

    MotorCommand_t       cmd;
    uint8_t              new_cmd    = MotorMsg_PollCommand(&cmd);

    /* 喂独立看门狗 —— 如果此处卡死，IWDG ~2s 后自动复位 MCU */
    IWDG_REFRESH();      /* 喂独立看门狗 —— IWDG 寄存器直接操作 */

    /* ================================================================
     *  第 1 步：处理新指令 → 模式切换 + 参数更新
     *
     *  校准模式中忽略其他指令（避免异常切换破坏校准流程）。
     *  收到 STANDBY 可随时中止校准。
     * ================================================================ */
    if (new_cmd)
    {
        g_comms_timeout = 0;    /* 收到新指令 → 复位通信超时 */

        /* ---- 校准中收到待机：中止校准 ---- */
        if (g_mode == MOTOR_MODE_CALIBRATE && cmd.mode == MOTOR_MODE_STANDBY)
        {
            FOC_Disable(&Motor);
            g_mode = MOTOR_MODE_STANDBY;
            LED_SetPattern(LED_PATTERN_HEARTBEAT);
        }
        /* ---- 校准中忽略其他指令 ---- */
        else if (g_mode == MOTOR_MODE_CALIBRATE)
        {
            /* 丢弃，保持校准状态 */
        }
        /* ---- 正常模式切换 ---- */
        else
        {
            /* 进入 / 退出待机 */
            if (cmd.mode == MOTOR_MODE_STANDBY && g_mode != MOTOR_MODE_STANDBY)
            {
                FOC_Disable(&Motor);
                g_speed_desired    = 0.0f;
                Motor.target_speed = 0.0f;
                LED_SetPattern(LED_PATTERN_HEARTBEAT);
            }
            else if (cmd.mode != MOTOR_MODE_STANDBY && g_mode == MOTOR_MODE_STANDBY)
            {
                /* 从待机恢复时，从当前实际转速起步（避免斜坡从旧值起跑） */
                Motor.target_speed = Motor.speed;
                FOC_Enable(&Motor);
            }

            g_mode = cmd.mode;

            switch (g_mode)
            {
            case MOTOR_MODE_STANDBY:
                break;

            case MOTOR_MODE_SPEED:
                g_speed_desired  = cmd.target * RAD_S_TO_RPM;
                g_speed_desired  = DATA_limit(g_speed_desired,
                                              -SPEED_LIMIT_RPM, SPEED_LIMIT_RPM);
                FOC_SetSpdExtPID(&Motor, cmd.spd_kp, cmd.spd_ki, 0.0f, Motor.Umax);
                break;

            case MOTOR_MODE_POSITION:
                FOC_SetTarget(&Motor, cmd.target * RAD_TO_DEG);
                FOC_SetPosPID(&Motor, cmd.pos_kp, 0.0f, cmd.pos_kd, 2000.0f);
                break;

            case MOTOR_MODE_CALIBRATE:
                /* 启动自校准：注入 Ud=4V 拉转子到 d 轴对齐 */
                Motor.calib_flag  = 1;
                Motor.calib_count = 0;
                LED_SetPattern(LED_PATTERN_FAST_BLINK);
                break;

            default:
                break;
            }
        }
    }

    /* ================================================================
     *  通信超时保护：超过 100ms 未收到指令 → 自动待机
     *
     *  （仅 SPEED / POSITION / TORQUE 模式生效，
     *   CALIBRATE 模式持续 ~3s 无指令，跳过超时检查）
     * ================================================================ */
    if (g_mode == MOTOR_MODE_SPEED || g_mode == MOTOR_MODE_POSITION
        || g_mode == MOTOR_MODE_TORQUE)
    {
        if (++g_comms_timeout >= 100)
        {
            FOC_Disable(&Motor);
            g_mode = MOTOR_MODE_STANDBY;
            g_speed_desired    = 0.0f;
            Motor.target_speed = 0.0f;
            LED_SetPattern(LED_PATTERN_HEARTBEAT);
        }
    }
    else
    {
        g_comms_timeout = 0;
    }

    /* ================================================================
     *  第 2 步：FOC 流水线（按模式执行不同控制环）
     * ================================================================ */
    FOC_UpdateSensor(&Motor);
    FOC_ReadCurrents(&Motor);       /* 读三相电流 → Clarke → Park → Id/Iq */

    switch (g_mode)
    {
    case MOTOR_MODE_STANDBY:
        break;

    case MOTOR_MODE_SPEED:
        /* 软启动：每周期把 target_speed 往 g_speed_desired 拉一步
         * SPEED_RAMP_RPM_S=0 时 step=0，退化为直通（编译器优化掉） */
        {
            float step = SPEED_RAMP_RPM_S / Motor.rate;  /* rpm/周期 */
            float err  = g_speed_desired - Motor.target_speed;
            if (err > step)
                Motor.target_speed += step;
            else if (err < -step)
                Motor.target_speed -= step;
            else
                Motor.target_speed = g_speed_desired;
        }
        FOC_SpdCtrl_Ext(&Motor);
        break;

    case MOTOR_MODE_POSITION:
        FOC_PosCtrl(&Motor);
        FOC_SpdCtrl(&Motor);
        break;

    case MOTOR_MODE_CALIBRATE:
        /* 跳过控制环 —— FOC_Output 内部的 calib_flag 会自动注入 Ud=4V */
        break;

    default:
        break;
    }

    FOC_Output(&Motor);

    /* ================================================================
     *  LED 指示器 —— 亮度来自扭矩，模式由事件驱动
     *
     *  亮度（Brightness）：
     *    待机/校准：强制 100%，不受扭矩影响（要闪烁可见）
     *    运行态：20%~100% 线性映射到 0~12V Uq
     *  模式（Pattern）：
     *    待机/校准时由模式切换事件设置，运行态默认常亮。
     * ================================================================ */
    {
        uint8_t brightness;
        if (g_mode == MOTOR_MODE_CALIBRATE) {
            brightness = 100;
            /* 校准已在进入时设为 FAST_BLINK */
        } else if (g_mode == MOTOR_MODE_STANDBY) {
            brightness = 100;
            /* 待机已在切换事件中设为 HEARTBEAT */
        } else {
            /* 运行态：5%~100% 对应 0~12V */
            float ratio = Motor.Uq / Motor.Umax;
            if (ratio < 0.0f)  ratio = -ratio;
            if (ratio > 1.0f)  ratio = 1.0f;
            brightness = 5 + (uint8_t)(ratio * 95.0f);
            LED_SetPattern(LED_PATTERN_ON);
        }
        LED_SetBrightness(brightness);
    }

    /* ================================================================
     *  第 3 步：校准完成检测
     *
     *  FOC_Output 中 calib_count 超过 3s 后自动清零 calib_flag，
     *  并将当前 pole_pairs × mech_angle 写入 elec_offset。
     *  此处检测到 flag 清零 → 写入 Flash → 恢复 LED → 关断 → 回待机。
     * ================================================================ */
    if (g_mode == MOTOR_MODE_CALIBRATE && Motor.calib_flag == 0)
    {
        /* 写入非易失存储永久保存 */
        Motor.storage->write(Motor.storage->ctx,
                             &Motor.elec_offset,
                             sizeof(Motor.elec_offset));

        LED_SetPattern(LED_PATTERN_HEARTBEAT);
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

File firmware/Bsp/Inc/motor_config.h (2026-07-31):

/**
 * @file    motor_config.h
 * @brief   电机硬件参数统一配置
 *
 * SPDX-License-Identifier: MIT
 * Copyright (c) 2024 The FOC Firmware Contributors
 *
 * 集中管理极对数、母线电压、控制频率等硬件参数。
 * 所有模块从此处读取唯一数据源，消除重复配置。
 */

#ifndef __MOTOR_CONFIG_H__
#define __MOTOR_CONFIG_H__

#include <stdint.h>

/**
 * @brief 速度限幅 (rpm)
 *
 * target_speed 被钳制在 ±此值内。
 * 龙伯格观测器的 x2_max 独立设为此值 x5（10000 rpm），
 * 确保观测器自身不限幅控制目标。
 */
#define SPEED_LIMIT_RPM     2000.0f

/**
 * @brief 速度模式软启动斜率 (rpm/s)
 *
 * 限制 target_speed 每秒最大变化量，防止指令跳变导致电流冲击。
 * 每 1ms 控制周期步进 = SPEED_RAMP_RPM_S / 1000。
 *
 * 例如：从 0→2000 rpm 需要 2000/500 = 4 秒。
 * 设为 0 可禁用软启动（target_speed 立即跟随指令）。
 */
#define SPEED_RAMP_RPM_S    500.0f

/**
 * @brief 电角度前馈补偿延迟时间 (s)
 *
 * 补偿从 AS5600 角度采样到 PWM 输出实际生效之间的总延迟。
 * 包括: I2C 读取 + 观测器计算 + PWM 影子寄存器更新。
 *
 * 在 FOC_Output 的反 Park 变换前，根据当前转速推算此期间转子转过的
 * 电角度，提前补偿，使电压矢量始终对准真实转子位置。
 *
 * 公式: angle_advance_deg = speed_rpm × pole_pairs × 6 × 此值
 * 1600 RPM, 7 极对: advance = 1600 × 7 × 6 × 0.00021 = 14.1°
 * 2000 RPM, 7 极对: advance = 2000 × 7 × 6 × 0.00021 = 17.6°
 *
 * 调节方法:
 *   太小 (<0.00015): 补偿不足, 高速时 Id 偏负, 速度上不去
 *   太大 (>0.00035): 过补偿, 高速时 Id 偏正, 可能振荡
 *   推荐从 0.00021 开始, 用 VOFA+ 观察 Id 随速度变化的趋势
 */
#define ANGLE_COMP_DELAY_S  0.00021f

/**
 * @brief 电压调制系数 —— 决定线性调制区最大相电压
 *
 * 实际限制值为 bus_voltage × 此系数。
 * 当 UqUd 矢量模长超过此值时做等比例缩小，避免进入过调制区。
 *
 * 选值：
 *   0.5f      = SPWM  线性调制上限 (Udc/2)
 *   0.57735f  = SVPWM 线性调制上限 (Udc/√3)
 *
 * 当前使用 SVPWM，故设为 0.57735f。
 * 若将来切回 SPWM，改成 0.5f 即可。
 */
#define VOLTAGE_MODULATION_FACTOR  0.577350269f

/**
 * @brief 电机硬件参数
 *
 * 在 main.c 中初始化后传递给 FOC_Init，PWM 驱动层不再关心母线电压。
 */
typedef struct
{
    uint8_t  pole_pairs;      /**< 极对数                      */
    float    bus_voltage;     /**< 母线电压 (V)                */
    float    rate_hz;         /**< 控制频率 (Hz)               */

} MotorConfig_t;

#endif

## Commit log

2026-07-21 Initial commit: PicoFOC - compact STM32F103 FOC motor drive platform
    - firmware/: dual-observer FOC control with CAN/UART communication
    - hardware/: PCB design (placeholder)
    - mechanical/: 3D enclosure (placeholder)
    - License: MIT
2026-07-21 docs: 重写顶层 README，补充硬件 README；feat: 添加 PCB 工程文件与 PDF 输出
2026-07-21 fix: 修复龙伯格观测器单位换算bug并切换为默认观测器
    - 切换默认观测器：ObserverDiff → ObserverLuenberger
    - 修复位置预测方程缺 rpm→deg/s 换算（x2_hat为rpm，需×6再乘Ts）
    - 调参：l1=0.5（快速跟踪，~2ms滞后），l2=1.0（速度轻柔）
    - Foc.c 位置+速度数据源统一使用观测器
    [Foc.c, main.c]
2026-07-21 feat: add mechanical design files and README
    Add:
    - STEP CAD source files (magnet holder, PCB covers, driver board, motor stator/rotor)
    - 3MF slicer files for 3D printing
    - mechanical/README.md with full documentation
    Update:
    - Top-level README.md with mechanical section and updated project tree
    [2804电机定子.step, 2804电机转子.step, PCB外壳1.3mf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]
2026-07-21 style: README 改为中英双语对照
    修改:
    - README.md 各章节改为中文在前、英文在后对照格式
    - 硬件章节增加英文标注(key)方便检索
2026-07-22 fix: 修复 PID 积分项积累速度过慢，通信协议文档归入 Docs/
    - pid.c - integral 去掉 ×dt 归一化，恢复正常积累速度；同步去掉微分项 /dt
    - pid.h - 更新字段注释 measure_error 为变化量（Delta）
    - Foc.c - SpdPID/SpdPID_Ext/SpdPID_Ext(Init) 的 integral_max 改为 1000.0f
    新增:
    - firmware/Docs/通信协议文档.md - 完整通信协议说明，含各字段数值范围/编码解码公式/指令示例/已知问题
    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
    [Foc.c]
2026-07-22 docs: 删除 Foc.c 中过时的 PID 时间归一化注释
    - Foc.c:77 注释提到 integral x dt 归一化，已不再适用，删除
    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
2026-07-22 fix: 恢复 PID 时间归一化（integral x dt），保留 integral_max=1000
    - pid.c: 恢复 integral += error x dt 归一化，恢复 D 项 /dt
    - pid.h: 加回时间归一化特性说明
    - Foc.c: 加回归一化注释
    分析:
    - 去掉 xdt 后 ki 被放大 1000x 导致震荡
    - 恢复归一化后协议 byte[7](ki 0~1.0) 自然匹配
    - integral_max=1000 保留不动（此前 12 太小是真正 bug）
    - measure_error 注释保留已纠正的'变化量(Delta)'
    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
    [Foc.c]
2026-07-22 feat: 添加安全保护机制（看门狗、CAN Bus-Off恢复、通信超时、输入校验）
2026-07-23 fix: 修复PCB铺铜bug + main.c IWDG寄存器直接操作
    - 修复PCB铺铜问题（PicoFOC.epro2）
    - main.c 改为IWDG寄存器直接操作，消除对HAL_IWDG源文件的依赖
    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
    [main.c]
2026-07-25 docs: 新增 PicoFOC 原理图 PDF
    hardware/ 目录新增：
    - 原理图_PicoFOC.pdf — 电路原理图，包含 MP6541 驱动电路、
    STM32F103C8T6 最小系统、AS5600 编码器接口、
    CAN/UART 通信接口、电源树等完整电路设计
2026-07-26 封存电流环 Phase1 全部改动 + 新增试错文档
2026-07-26 docs: 新增电流环试错经验 + 未完成计划文档到 Docs/
2026-07-28 deepseek的修改 改动总结（5 个文件，+72/-25 行）
    IWDG 独立看门狗初始化（main.c + main.h）
    问题：HAL_IWDG_MODULE_ENABLED 在 stm32f1xx_hal_conf.h 中被注释掉了，IWDG 从未被配置。代码虽然到处喂狗（IWDG_REFRESH()），但如果看门狗根本没启动，所有故障 handler 里写的「等待 IWDG ~2s 后复位」都是空话。
    修改：新增 IWDG_Init() 函数，通过直接寄存器操作配置：LSI 40kHz → 预分频 /256 → 重装载 312 → 超时 ≈ 2.0s；在 TIM_RegisterCallback() 之后、while(1) 之前调用，确保所有初始化完成后才启动看门狗；把 IWDG_REFRESH() 宏从 main.c 和 motor_ctrl.c 的重复定义提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
    [main.c, motor_ctrl.c]
2026-07-28 fix: IWDG_Init 缺少 LSI 先启动后等就绪 + 文档同步修复
    IWDG_Init:
    - 先 RCC->CSR |= RCC_CSR_LSION 开启 LSI 时钟，再等 LSIRDY
    - 修复 ai 合入代码中缺少 LSI 开启可能导致死机的 bug
    - Error_Handler LED 注释 ~200ms 更正为 ~110ms
    通信协议文档:
    - §3.1.2 target NaN/Inf 校验已实现，正文同步
    - §2.2 UART 自定义协议频率 100Hz→1kHz
    - §4 VOFA 发送频率 100Hz→全速受互斥锁限制
    [main.c]
2026-07-30 perf: SpdPID Kp 0.01→0.1 提升位置环刚性 + 文档/工具完善
    关键改动：
    - SpdPID Kp 0.01→0.1（50rpm 速度误差 P 项从 0.5V→5V），
    解决稳态附近 P 项太弱、全靠积分慢爬的刚性差问题
    - 同时修复 IWDG_Init 缺少前向声明导致编译报错（Keil C89）
    Docs:
    - 通信协议文档.md 重构八大节，修正编码系数，补充 CRC16 参考实现
    - 新增 学习指南-代码架构与核心技能.md
    Tools:
    - 新增 protocol_tool.html（CAN/UART 控制帧编解码 + CRC16）
    [main.c]
2026-07-31 fix: PID back-calculation anti-windup + speed ramp soft-start
    PID anti-windup rewritten (pid.c):
    - Old: conditionally freeze integral when output saturated.
    Bug: during acceleration, P alone saturates output so integral gets
    locked at ~2.0 permanently. Changing Ki had no visible effect.
    - New: back-calculation anti-windup. When output saturates, recalculate
    integral = (output_max - P - D) / ki, keeping only what is needed
    to fill the gap after P and D.
    - Effect: changing Ki immediately noticeable, smooth P-to-I transition.
    Speed mode soft-start (motor_ctrl + motor_config.h):
    - Added SPEED_RAMP_RPM_S=500: limits target_speed change to 500 rpm/s
    - Zero g_speed_desired and target_speed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
    [motor_config.h, motor_ctrl.c]
2026-07-31 feat: spd_ki 解码增益 ×10，data[7]=0xFF → Ki=10.0（原 1.0）
    独立速度环积分力度放大 10 倍，低速负载下积分积累更快，手捏电机时
    I 项能在更短时间内输出足够扭矩抵抗负载。
    pos_kd 不受影响（仍为 0~1），仅 spd_ki 范围变为 0~10。
    Kp 范围不变（0~10）。
    协议兼容：上位机字节格式不变，仅电机侧解码系数变化。
    上位机工具需更新 Ki 显示范围。
2026-07-31 fix: protocol_tool 速度指令转换错误 + Ki 范围适配 ×10
    Bug 1（速度转换）：
    单位按钮的 data-unit 属性硬编码为 deg/rad，切到 SPEED 模式后
    只改了按钮文字没改 data-unit → 点击 rpm 按钮时 targetUnit 变成
    deg → getTargetRad() 中 targetUnit==='rpm' 永远不成立 → 值当
    rad/s 直传，完全不转换。
    修复：updateTargetUnit() 中同步更新 data-unit 属性。
    Bug 2（Ki 范围）：
    spd_ki 解码系数已 ×10（0xFF → Ki=10.0），但网页滑条仍是 0~1
    且编码未适配新模式。
    修复：SPEED 模式下滑条范围 0~10、标签改为 Ki 积分增益、
    编码公式改用 raw=round(ki/(KD_DEC×10))。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
